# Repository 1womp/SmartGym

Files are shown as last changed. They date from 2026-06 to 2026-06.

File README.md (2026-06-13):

# SmartGym Adaptive Training System

Language: English | [Espanol](README.es.md)

SmartGym is an ESP32-S3 adaptive training prototype for selectorized gym machines. It combines RFID user identification, a touchscreen LVGL interface, range-of-motion tracking, rep and set detection, guided calibration, user-specific load recommendations, Firebase Realtime Database synchronization, a React dashboard, and a separate weight-detection prototype.

The current repository keeps the PlatformIO firmware project at the repository root so the existing build commands and include paths continue to work. Companion project assets are organized in `dashboard/`, `weight_detection/`, `docs/`, `hardware/`, and `screenshots/`.

## Start Here

If you are new to the project, start with [docs/START_HERE.md](docs/START_HERE.md). It explains what to read first, where every subsystem lives, and how the data flows from sensors to Firebase and the dashboard.

Fast paths:

| Goal | Open |
| --- | --- |
| Build and upload firmware | [Developer Guide](docs/DEVELOPER_GUIDE.md) |
| Understand ROM, calibration, equations, and error sources | [Measurement and Calibration Guide](docs/MEASUREMENT_AND_CALIBRATION_GUIDE.md) |
| Use the device in a demo | [User Manual](docs/USER_MANUAL.md) |
| Configure Firebase and understand upload paths | [Firebase Guide](docs/FIREBASE_GUIDE.md) |
| Understand dashboard seed/test data | [Firebase Dashboard Seed Guide](docs/FIREBASE_DASHBOARD_SEED_GUIDE.md) |
| Find CAD/STL hardware files | [hardware/cad/README.md](hardware/cad/README.md) |
| Run the web dashboard | [dashboard/README.md](dashboard/README.md) |
| Test the VL53L0X prototype | [weight_detection/README.md](weight_detection/README.md) |

## Key Features

- RFID user identification with MFRC522.
- ESP32-S3 touchscreen interface using LVGL.
- Analog ROM tracking with 5 ms sensor sampling, approximately 200 Hz.
- Live motion graph refreshed at approximately 16 ms, about 60 Hz.
- Rep and set detection from normalized ROM.
- Guided calibration for user-specific ROM and load recommendations.
- Manual machine pin load model: the user updates the physical pin value with buttons.
- Separate user-specific recommended load.
- Firebase RTDB sync for profiles, calibration, sessions, summaries, and device heartbeat.
- Local NVS upload queue for offline/retry behavior.
- Web dashboard for Firebase workout data.
- Separate VL53L0X weight-detection prototype module.

## System Architecture

```mermaid
flowchart LR
  Sensor[Motion sensor] --> ESP32[ESP32-S3 firmware]
  RFID[RFID reader] --> ESP32
  Touch[Touchscreen UI] <--> ESP32
  ESP32 --> NVS[Local NVS queue]
  ESP32 --> Firebase[Firebase RTDB]
  Firebase --> Dashboard[React dashboard]
  Weight[VL53L0X weight detection prototype] -. future integration .-> ESP32
```

The firmware reads motion, normalizes ROM, detects reps, records sessions, computes summary metrics, updates recommendations, stores pending uploads locally, and synchronizes with Firebase. The dashboard reads Firebase paths to visualize user training history.

## Hardware List

- ESP32-S3 VIEWE 7 inch display board.
- RGB touchscreen display supported by ESP32 Display Panel and LVGL.
- MFRC522 RFID reader.
- Analog motion/position sensor connected to GPIO 17.
- Optional VL53L0X distance sensor for the teammate weight-detection prototype.
- Selectorized gym machine with physical weight pin.
- Wi-Fi network with Firebase RTDB access.

## Software Stack

- PlatformIO.
- Arduino framework for ESP32.
- LVGL 8.4.0.
- ESP32_Display_Panel and ESP32_IO_Expander.
- MFRC522.
- FirebaseClient and ESP_SSLClient.
- React, Vite, Firebase Web SDK, and Recharts for the dashboard.

## Repository Structure

```text
.
|-- boards/                 PlatformIO board definition
|-- dashboard/              Teammate React/Vite Firebase dashboard
|-- docs/                   User, developer, Firebase, architecture, troubleshooting docs
|-- firebase_seed/          Safe Firebase seed/import artifacts
|-- hardware/               Wiring and sensor notes
|-- lib/                    Firmware libraries
|-- sample_data/            Firebase/sample data artifacts
|-- screenshots/            Screenshots or demo photos
|-- scripts/                Utility scripts
|-- src/                    Firmware application source
|-- tools/                  Local tooling
|-- weight_detection/       Teammate VL53L0X weight-detection prototype
|-- platformio.ini          Firmware build configuration
`-- README.md
```

## What Each Folder Is For

| Folder | Purpose |
| --- | --- |
| `src/` and `lib/` | ESP32-S3 firmware application and support modules. |
| `docs/` | Human-readable guides for usage, architecture, calibration, Firebase, and troubleshooting. |
| `hardware/` | Wiring notes plus CAD/STL files for mounts, enclosure parts, and ToF hardware. |
| `dashboard/` | React/Vite dashboard that reads Firebase workout data. |
| `firebase_seed/` | Safe Firebase seed/import artifacts and import instructions. |
| `weight_detection/` | Standalone VL53L0X prototype sketch for weight-stack detection experiments. |
| `sample_data/` | Firebase/sample data artifacts used for testing and dashboard demos. |
| `screenshots/` | Demo photos, UI screenshots, dashboard captures, and wiring images. |
| `tools/` and `scripts/` | Local generation, validation, and documentation utilities. |

## Documentation

The full documentation package is indexed in [docs/README.md](docs/README.md).

Most important PDFs:

- [User Manual](docs/USER_MANUAL.pdf)
- [System Architecture](docs/SYSTEM_ARCHITECTURE.pdf)
- [Developer Guide](docs/DEVELOPER_GUIDE.pdf)
- [Measurement and Calibration Guide](docs/MEASUREMENT_AND_CALIBRATION_GUIDE.md)
- [Firebase Guide](docs/FIREBASE_GUIDE.pdf)
- [Firebase Dashboard Seed Guide](docs/FIREBASE_DASHBOARD_SEED_GUIDE.md)
- [Troubleshooting Guide](docs/TROUBLESHOOTING.pdf)

## Quick Start

### Firmware

Install PlatformIO, connect the ESP32-S3 display board, then build:

```powershell
python -m platformio run --environment BOARD_VIEWE_UEDX80480070E_WB_A
```

Upload and monitor:

```powershell
python -m platformio run --target upload --target monitor --environment BOARD_VIEWE_UEDX80480070E_WB_A
```

### Dashboard

```powershell
cd dashboard
npm install
copy .env.example .env
npm run dev
```

Fill `.env` with the Firebase web config before running. Open the local Vite URL shown in the terminal. The dashboard reads Firebase RTDB data such as `usersByRfid` and `athleteWeeklySessions`.

### Weight Detection Prototype

The VL53L0X prototype is in `weight_detection/`. It is not merged into the firmware. Use it as a separate Arduino sketch for validating optical/distance-based weight-stack detection.

## Device Usage Overview

1. Power on the ESP32 display.
2. Wait for UI, Wi-Fi, Firebase, RFID, and time services.
3. Scan an RFID card.
4. Wait until the loading popup finishes profile, calibration, recommendation, and ROM mapping.
5. Check the pin load and recommended load.
6. Physically move the machine pin if desired, then update the pin load with the four buttons.
7. Press START.
8. Follow the motion graph and timing cues.
9. Finish the workout or let target sets complete.
10. Review the summary while the session syncs.

## Calibration Overview

Calibration is user-specific and machine-type-specific. It records clean reps at one or more loads, estimates ROM and performance quality, and saves recommended loads under `calibrations/{uid}/{machineTypeId}`. The physical pin is never moved automatically by software; the user adjusts the machine pin and confirms the displayed pin load.

For the full signal path, formulas, ROM normalization logic, calibration flow,
error sources, and validation steps, see
[docs/MEASUREMENT_AND_CALIBRATION_GUIDE.md](docs/MEASUREMENT_AND_CALIBRATION_GUIDE.md).

## Data Model Overview

Primary Firebase nodes:

- `usersByRfid/{uid}`
- `calibrations/{uid}/{machineTypeId}`
- `machineConfigs/{machineId}`
- `athleteWeeklySessions/{uid}/{weekKey}/days/{dayKey}`
- `devices/{deviceId}`

Session uploads include a root session record, daily metadata, timeline entries, day/week summaries, representative reps, set details, and per-set rep details under `repSets`.

## Known Limitations

- The firmware currently uses a manual pin load model; there is no integrated physical weight sensor in the main firmware.
- Firebase/TLS writes are memory-sensitive on ESP32, so uploads are queued and chunked.
- Dashboard Firebase configuration is loaded from local environment variables and should not be committed.
- The weight-detection module is a prototype and requires machine-specific calibration.

## Future Improvements

- Integrate physical weight detection after validation.
- Add production Firebase security rules and auth flow.
- Add automated firmware integration tests where practical.
- Add dashboard deployment instructions and screenshots.
- Add machine-specific wiring diagrams.

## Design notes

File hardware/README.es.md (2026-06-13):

# Notas De Hardware

Idioma: [English](README.md) | Espanol

## Hardware Principal Del Firmware

- Pantalla ESP32-S3 VIEWE de 7 pulgadas.
- Pantalla tactil RGB usando ESP32 Display Panel y LVGL.
- Lector RFID MFRC522.
- Sensor analogico ROM/motion conectado a GPIO 17.
- Red Wi-Fi para sincronizacion Firebase RTDB.

## Pines Del Firmware

Constantes actuales:

- Entrada de sensor de movimiento: GPIO 17.
- Intervalo de muestreo: 5 ms.
- RFID SS: GPIO 10.
- RFID SCK: GPIO 12.
- RFID MISO: GPIO 13.
- RFID MOSI: GPIO 11.
- RFID reset no usa pin dedicado.

## CAD E Impresion 3D

Archivos SolidWorks editables y exportes STL para mounts y enclosure estan en [`hardware/cad`](cad/).

Para ROM, conversion de senal, calibracion, fuentes de error y validacion, lee [`docs/MEASUREMENT_AND_CALIBRATION_GUIDE.es.md`](../docs/MEASUREMENT_AND_CALIBRATION_GUIDE.es.md).

## Prototipo De Deteccion De Peso

El modulo separado `weight_detection/` usa VL53L0X:

- VCC -> 3.3 V.
- GND -> GND.
- SDA -> GPIO 21.
- SCL -> GPIO 22.

Este prototipo no forma parte del firmware principal de produccion todavia.

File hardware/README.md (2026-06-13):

# Hardware Notes

Language: English | [Espanol](README.es.md)

## Main Firmware Hardware

- ESP32-S3 VIEWE 7 inch display board.
- RGB touchscreen display using ESP32 Display Panel and LVGL.
- MFRC522 RFID reader.
- Analog ROM/motion sensor connected to GPIO 17.
- Wi-Fi network for Firebase RTDB sync.

## Firmware Pin Notes

Current firmware constants:

- Motion sensor input: GPIO 17.
- Sensor sample interval: 5 ms.
- RFID SS: GPIO 10.
- RFID SCK: GPIO 12.
- RFID MISO: GPIO 13.
- RFID MOSI: GPIO 11.
- RFID reset is not used as a dedicated pin.

## CAD and 3D Printing Files

Editable SolidWorks parts and STL exports for the prototype mounts and display
enclosure are available in [`hardware/cad`](cad/).

For the full explanation of ROM measurement, signal conversion, calibration,
error sources, and validation, see
[`docs/MEASUREMENT_AND_CALIBRATION_GUIDE.md`](../docs/MEASUREMENT_AND_CALIBRATION_GUIDE.md).

## Weight Detection Prototype

The separate `weight_detection/` module uses a VL53L0X sensor:

- VCC -> 3.3 V.
- GND -> GND.
- SDA -> GPIO 21.
- SCL -> GPIO 22.

This prototype is not part of the production firmware path yet.

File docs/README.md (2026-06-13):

# SmartGym Documentation

Language: English | [Espanol](README.es.md)

This folder contains the documentation package for the SmartGym v1.0 prototype. Each major guide is available as editable Markdown and as a formatted PDF.

## Start Here

- [Start Here](START_HERE.md)
- [Project README](../README.md)
- [User Manual](USER_MANUAL.md) | [PDF](USER_MANUAL.pdf)
- [System Architecture](SYSTEM_ARCHITECTURE.md) | [PDF](SYSTEM_ARCHITECTURE.pdf)
- [Developer Guide](DEVELOPER_GUIDE.md) | [PDF](DEVELOPER_GUIDE.pdf)
- [Measurement and Calibration Guide](MEASUREMENT_AND_CALIBRATION_GUIDE.md)
- [Firebase Guide](FIREBASE_GUIDE.md) | [PDF](FIREBASE_GUIDE.pdf)
- [Troubleshooting Guide](TROUBLESHOOTING.md) | [PDF](TROUBLESHOOTING.pdf)

## Reference Documents

| Document | Markdown | PDF |
| --- | --- | --- |
| Start Here | [Open](START_HERE.md) | PDF can be generated locally |
| Measurement and Calibration Guide | [Open](MEASUREMENT_AND_CALIBRATION_GUIDE.md) | PDF can be generated locally |
| Firebase Dashboard Seed Guide | [Open](FIREBASE_DASHBOARD_SEED_GUIDE.md) | [PDF](FIREBASE_DASHBOARD_SEED_GUIDE.pdf) |
| Firebase Dashboard Seed Guide ES | [Abrir](FIREBASE_DASHBOARD_SEED_GUIDE.es.md) | PDF can be generated locally |

## Find Information By Task

| Task | Best Document |
| --- | --- |
| Understand the whole project quickly | [Start Here](START_HERE.md) |
| Operate the physical device | [User Manual](USER_MANUAL.md) |
| Explain ROM, calibration, formulas, noise, and errors | [Measurement and Calibration Guide](MEASUREMENT_AND_CALIBRATION_GUIDE.md) |
| Understand firmware modules and runtime flow | [System Architecture](SYSTEM_ARCHITECTURE.md) |
| Build, upload, debug, or modify firmware | [Developer Guide](DEVELOPER_GUIDE.md) |
| Understand Firebase paths and upload phases | [Firebase Guide](FIREBASE_GUIDE.md) |
| Understand Firebase/dashboard seed data | [Firebase Dashboard Seed Guide](FIREBASE_DASHBOARD_SEED_GUIDE.md) |
| Diagnose failed builds, RFID, ROM, sync, or dashboard issues | [Troubleshooting Guide](TROUBLESHOOTING.md) |
| Find 3D-printable files and CAD sources | [Hardware CAD README](../hardware/cad/README.md) |
| Run the dashboard | [Dashboard README](../dashboard/README.md) |
| Use the standalone ToF prototype | [Weight Detection README](../weight_detection/README.md) |

## Recommended Reading Order

1. Read [Start Here](START_HERE.md) for the project map.
2. Read the [User Manual](USER_MANUAL.md) to understand how the device is used.
3. Read the [Measurement and Calibration Guide](MEASUREMENT_AND_CALIBRATION_GUIDE.md) to understand ROM, rep detection, calibration, and error sources.
4. Read the [System Architecture](SYSTEM_ARCHITECTURE.md) for the full data flow.
5. Read the [Developer Guide](DEVELOPER_GUIDE.md) before changing firmware.
6. Read the [Firebase Guide](FIREBASE_GUIDE.md) before importing, editing, or migrating database data.
7. Read the [Firebase Dashboard Seed Guide](FIREBASE_DASHBOARD_SEED_GUIDE.md) before loading demo dashboard data.
8. Use the [Troubleshooting Guide](TROUBLESHOOTING.md) during demos and hardware testing.

## Regenerating PDFs

Run this from the repository root:

```powershell
python tools/generate_docs_pdfs.py
```

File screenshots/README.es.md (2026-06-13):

# Capturas

Idioma: [English](README.md) | Espanol

Coloca en esta carpeta capturas del proyecto, imagenes del dashboard, fotos de cableado e imagenes de demo.

Archivos sugeridos:

- `main-ui-ready.jpg`
- `main-ui-training.jpg`
- `calibration-screen.jpg`
- `summary-sync.jpg`
- `dashboard-overview.jpg`

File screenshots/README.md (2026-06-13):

# Screenshots

Language: English | [Espanol](README.es.md)

Place project screenshots, dashboard captures, wiring photos, and demo images in this folder.

Suggested files:

- `main-ui-ready.jpg`
- `main-ui-training.jpg`
- `calibration-screen.jpg`
- `summary-sync.jpg`
- `dashboard-overview.jpg`

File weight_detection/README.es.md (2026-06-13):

# Prototipo De Deteccion De Peso

Idioma: [English](README.md) | Espanol

Esta carpeta contiene un prototipo independiente para detectar la posicion fisica del stack de pesas con un sensor de distancia VL53L0X.

Esta separado intencionalmente del firmware principal SmartGym. El firmware principal actualmente usa un modelo manual de pin load, donde el usuario actualiza la carga mostrada con botones tactiles.

## Que Hace

- Lee distancia desde VL53L0X por I2C.
- Promedia 30 muestras por ciclo.
- Mapea rangos de distancia a posiciones del stack.
- Mapea posiciones a peso detectado en libras.
- Confirma peso final despues de detecciones consistentes.
- Imprime distancia, stack, peso detectado, peso confirmado y estado por Serial.

## Hardware

- ESP32 o board Arduino compatible.
- Sensor VL53L0X.
- Cableado recomendado:
  - VCC -> 3.3 V
  - GND -> GND
  - SDA -> GPIO 21
  - SCL -> GPIO 22

## Dependencias

Instala la libreria Adafruit VL53L0X en Arduino IDE o PlatformIO:

- `Adafruit_VL53L0X`

## Como Correrlo

1. Abre `weight_detection_vl53l0x.ino` en Arduino IDE.
2. Instala la libreria VL53L0X.
3. Selecciona board y puerto ESP32.
4. Sube el sketch.
5. Abre Serial Monitor a 115200 baud.

## Salida Esperada

Serial imprime:

- distancia promedio en cm
- peso detectado en lb
- peso final confirmado
- contador de confirmacion
- numero de stack
- mensajes de estado

## Relacion Con Firmware SmartGym

El modulo puede convertirse en reemplazo o apoyo para entrada manual de pin load. Antes de integrarlo, los rangos distancia-peso deben calibrarse para la geometria exacta de la maquina.

## Limitaciones

- Rangos de distancia hard-coded y especificos por maquina.
- Valores actuales en libras, mientras la UI principal usa kg.
- No esta integrado con Firebase.
- No cambia recomendaciones SmartGym.
- No debe mezclarse al firmware hasta estabilizar montaje fisico y conversion.

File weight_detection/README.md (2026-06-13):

# Weight Detection Prototype

Language: English | [Espanol](README.es.md)

This folder contains a standalone teammate prototype for detecting the physical weight-stack position with a VL53L0X time-of-flight distance sensor.

It is intentionally kept separate from the main ESP32 SmartGym firmware. The production firmware currently uses a manual machine pin load model, where the user updates the displayed pin load with the touchscreen buttons.

## What It Does

- Reads distance from a VL53L0X sensor over I2C.
- Averages 30 samples per measurement cycle.
- Maps distance ranges to stack positions.
- Maps stack positions to detected weight values in pounds.
- Confirms the final detected weight after repeated consistent detections.
- Prints distance, detected stack, detected weight, final confirmed weight, and status to Serial.

## Hardware

- ESP32 or compatible Arduino board.
- VL53L0X distance sensor.
- Recommended wiring in the sketch:
  - VCC -> 3.3 V
  - GND -> GND
  - SDA -> GPIO 21
  - SCL -> GPIO 22

## Dependencies

Install the Adafruit VL53L0X library in Arduino IDE or PlatformIO:

- `Adafruit_VL53L0X`

## How to Run

1. Open `weight_detection_vl53l0x.ino` in Arduino IDE.
2. Install the VL53L0X library.
3. Select the ESP32 board and port.
4. Upload the sketch.
5. Open Serial Monitor at 115200 baud.

## Expected Output

The serial monitor prints:

- Average distance in cm.
- Detected weight in lb.
- Final confirmed weight.
- Confirmation counter.
- Detected stack number.
- Status messages.

## Relationship to SmartGym Firmware

The module can become a future replacement or helper for manual pin-load entry. Before integration, the distance-to-weight ranges must be calibrated for the exact machine geometry and weight stack.

## Limitations

- Distance ranges are hard-coded and machine-specific.
- Values are currently in pounds, while the main firmware UI uses kg.
- The module is not integrated with Firebase.
- The module does not change SmartGym recommendations.
- The module should not be merged into firmware until the physical sensor mounting and conversion model are stable.

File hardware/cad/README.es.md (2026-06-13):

# Archivos CAD SmartGym

Idioma: [English](README.md) | Espanol

Esta carpeta contiene archivos SolidWorks, STEP y STL usados para mounts, piezas impresas y enclosure del prototipo.

## Buscador Rapido

| Necesidad | Usar |
| --- | --- |
| Montar el encoder draw-wire | `encodermount.STL` |
| Sujetar hardware a la maquina | `gymmachineclamp.STL` |
| Imprimir enclosure de pantalla | `screen7inchbackplate.STL`, `screen7inchcover.STL`, `screen7inchfrontcover.STL` |
| Montar el sensor ToF | `tof_sensor_holder_nuevo_en mm.STL`, `Fastener.stl`, `Target.stl` |
| Editar CAD fuente | archivos `.SLDPRT` o `.step` |

## Lista Completa

| Archivo | Descripcion |
| --- | --- |
| `encodermount.SLDPRT` | Fuente SolidWorks del mount del encoder. |
| `encodermount.STL` | Export imprimible del mount del encoder. |
| `gymmachineclamp.SLDPRT` | Fuente SolidWorks del clamp de maquina. |
| `gymmachineclamp.STL` | Export imprimible del clamp. |
| `machinetube.SLDPRT` | Referencia/modelo del tubo de maquina. |
| `screen7inch.SLDPRT` | Referencia de pantalla de 7 pulgadas. |
| `screen7inchbackplate.STL` | Placa trasera imprimible. |
| `screen7inchcover.STL` | Cover imprimible de pantalla. |
| `screen7inchfrontcover.SLDPRT` | Fuente SolidWorks del frente de pantalla. |
| `screen7inchfrontcover.STL` | Export imprimible del frente. |
| `Target.step` | Fuente STEP de target ToF. |
| `Target.stl` | Export imprimible de target ToF. |
| `Fastener.step` | Fuente STEP del fastener ToF. |
| `Fastener.stl` | Export imprimible del fastener ToF. |
| `tof_sensor_holder_nuevo_en mm.SLDPRT` | Fuente SolidWorks del holder ToF actualizado. |
| `tof_sensor_holder_nuevo_en mm.STL` | Export imprimible del holder ToF actualizado. |

Los `.SLDPRT` y `.step` son editables. Los `.STL` son para slicing e impresion 3D.

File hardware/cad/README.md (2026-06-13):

# SmartGym CAD Files

Language: English | [Espanol](README.es.md)

This folder contains the SolidWorks part files and STL exports used for the
prototype hardware mounts and 3D-printed enclosure pieces.

## Files

## Quick Finder

| Need | Use |
| --- | --- |
| Mount the draw-wire encoder | `encodermount.STL` |
| Clamp hardware to the gym machine | `gymmachineclamp.STL` |
| Print the display enclosure | `screen7inchbackplate.STL`, `screen7inchcover.STL`, `screen7inchfrontcover.STL` |
| Mount the ToF sensor | `tof_sensor_holder_nuevo_en mm.STL`, `Fastener.stl`, `Target.stl` |
| Edit CAD sources | `.SLDPRT` or `.step` files |

## Full File List

| File | Description |
| --- | --- |
| `encodermount.SLDPRT` | SolidWorks source for the draw-wire encoder mount. |
| `encodermount.STL` | 3D-printable encoder mount export. |
| `gymmachineclamp.SLDPRT` | SolidWorks source for the gym machine clamp. |
| `gymmachineclamp.STL` | 3D-printable gym machine clamp export. |
| `machinetube.SLDPRT` | SolidWorks source for the machine tube reference/model. |
| `screen7inch.SLDPRT` | SolidWorks source/reference model for the 7-inch display. |
| `screen7inchbackplate.STL` | 3D-printable rear plate for the 7-inch display enclosure. |
| `screen7inchcover.STL` | 3D-printable display cover export. |
| `screen7inchfrontcover.SLDPRT` | SolidWorks source for the display front cover. |
| `screen7inchfrontcover.STL` | 3D-printable display front cover export. |
| `Target.step` | STEP source for the ToF target piece. |
| `Target.stl` | 3D-printable export for the ToF target piece. |
| `Fastener.step` | STEP source for the ToF holder fastener. |
| `Fastener.stl` | 3D-printable export for the ToF holder fastener. |
| `tof_sensor_holder_nuevo_en mm.SLDPRT` | SolidWorks source for the updated ToF sensor holder. |
| `tof_sensor_holder_nuevo_en mm.STL` | 3D-printable export for the updated ToF sensor holder. |

The `.SLDPRT` files are editable CAD sources. The `.STL` files are exported
for slicing and 3D printing.

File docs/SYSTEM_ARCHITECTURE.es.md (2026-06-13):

# Arquitectura Del Sistema SmartGym

Idioma: [English](SYSTEM_ARCHITECTURE.md) | Espanol

## Arquitectura General

```mermaid
flowchart LR
  Motion[Sensor de movimiento] --> SensorManager
  SensorManager --> ROM[Normalizacion ROM]
  ROM --> RepDetector
  RepDetector --> SessionRecorder
  RFID[Lector RFID] --> UserSync[Sync de usuario]
  UserSync --> Recommendation
  Recommendation --> UI[UI LVGL]
  SessionRecorder --> UploadQueue[Cola NVS]
  UploadQueue --> Firebase[Firebase RTDB]
  Firebase --> Dashboard[Dashboard React]
```

El sistema se divide en firmware embebido, Firebase RTDB y visualizacion en dashboard.

## Flujo De Datos

1. El sensor se muestrea cada 5 ms.
2. `SensorManager` filtra el valor analogico.
3. El firmware convierte la lectura a porcentaje ROM.
4. La calibracion de usuario mapea ROM crudo a ROM normalizado.
5. `RepDetector` identifica fases y repeticiones completas.
6. `SessionRecorder` guarda reps, sets, peso, ROM, tiempos y calidad.
7. `SmartGymTouchApp` calcula resumen y recomendacion.
8. La cola de subida guarda payloads Firebase.
9. `FirebaseService` envia escrituras seguras a RTDB.
10. El dashboard lee Firebase para graficas y resumenes.

## Flujo De Login

```mermaid
sequenceDiagram
  participant U as Usuario
  participant R as RFID
  participant D as Dispositivo
  participant F as Firebase
  U->>R: Escanea tarjeta
  R->>D: UID
  D->>D: Muestra popup de carga
  D->>F: Lee usersByRfid/{uid}
  F-->>D: Perfil
  D->>F: Lee calibrations/{uid}/{machineTypeId}
  F-->>D: Calibracion o missing
  D->>D: Resuelve recomendacion
  D->>D: Aplica mapeo ROM
  D->>D: Oculta popup
```

Las entradas quedan bloqueadas hasta que el sync termina o cae a un fallback seguro.

## Flujo De Entrenamiento

```mermaid
sequenceDiagram
  participant U as Usuario
  participant D as Dispositivo
  participant S as SessionRecorder
  participant Q as Cola
  participant F as Firebase
  U->>D: Presiona START
  D->>S: Inicia sesion con pin load
  U->>D: Hace reps
  D->>S: Registra reps y sets
  U->>D: Termina o auto-finish
  D->>S: Cierra sesion
  D->>Q: Encola subida
  Q->>F: Sube por fases
```

## Pin Load Vs Recomendacion

Pin load es estado fisico de la maquina. Permanece con la maquina entre usuarios. La recomendacion es consejo especifico por usuario.

El firmware nunca cambia pin load por una recomendacion. El usuario mueve fisicamente el pin y actualiza la UI con botones.

## Calibracion

La calibracion usa el pin load actual y cargas sugeridas. El usuario confirma la carga fisica antes de recolectar reps. El firmware analiza repeticiones suaves, estima si la carga es adecuada y guarda datos de calibracion por usuario y maquina.

## Sync

El final de sesion agenda sync. Trabajo pesado de Firebase no ocurre dentro del cierre inmediato.

Fases:

- Core de sesion.
- Metadata.
- Timeline.
- Resumenes.
- Detalles.
- Rep sets.

La cola NVS permite reintentos y evita perdida de datos si Firebase o Wi-Fi fallan temporalmente.

## Frecuencias

- Tick principal: 4 ms.
- Muestreo sensor: 5 ms, aproximadamente 200 Hz.
- Grafica: 16 ms, aproximadamente 60 Hz.
- UI lenta: 140 ms.
- UI debug: 160 ms.
- Servicio cloud normal: 5000 ms.
- Cadencia de finish sync: aproximadamente 1200 ms.
- Heartbeat: 60000 ms.
- Timeout user sync: 12000 ms.

## Estrategia De Memoria

El ESP32-S3 tiene poca memoria durante escrituras TLS/Firebase. El firmware mide heap interno y bloque interno mas grande, y elige modo:

- Normal: payloads mas grandes.
- Constrained: payloads pequenos y repSets fragmentados.
- Critical: payloads muy pequenos o backoff.

Objetos LVGL opcionales se liberan antes de entrenamiento/subida para mejorar heap disponible.

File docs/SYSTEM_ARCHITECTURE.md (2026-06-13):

# SmartGym System Architecture

Language: English | [Espanol](SYSTEM_ARCHITECTURE.es.md)

## High-Level Architecture

```mermaid
flowchart LR
  Motion[Motion Sensor] --> SensorManager
  SensorManager --> ROM[ROM Normalization]
  ROM --> RepDetector
  RepDetector --> SessionRecorder
  RFID[RFID Reader] --> UserSync[User Sync]
  UserSync --> Recommendation
  Recommendation --> UI[LVGL UI]
  SessionRecorder --> UploadQueue[NVS Upload Queue]
  UploadQueue --> Firebase[Firebase RTDB]
  Firebase --> Dashboard[React Dashboard]
```

The system is split into embedded firmware, Firebase RTDB, and dashboard visualization.

## Data Flow

1. Sensor is sampled every 5 ms.
2. SensorManager filters the analog value.
3. Firmware converts sensor reading to ROM percentage.
4. User calibration maps raw ROM into user-normalized ROM.
5. RepDetector identifies rep phases and completed reps.
6. SessionRecorder stores reps, sets, weight, ROM, timing, and quality.
7. SmartGymTouchApp computes summary/recommendation updates.
8. Upload queue stores Firebase payloads.
9. FirebaseService sends memory-safe writes to RTDB.
10. Dashboard reads Firebase for charts and summaries.

## User Login Flow

```mermaid
sequenceDiagram
  participant U as User
  participant R as RFID
  participant D as Device
  participant F as Firebase
  U->>R: Scan card
  R->>D: UID
  D->>D: Show loading popup
  D->>F: Fetch usersByRfid/{uid}
  F-->>D: Profile
  D->>F: Fetch calibrations/{uid}/{machineTypeId}
  F-->>D: Calibration or missing
  D->>D: Resolve recommendation
  D->>D: Apply ROM mapping
  D->>D: Hide loading popup
```

Inputs are blocked until sync completes or falls back safely.

## Workout Flow

```mermaid
sequenceDiagram
  participant U as User
  participant D as Device
  participant S as SessionRecorder
  participant Q as Upload Queue
  participant F as Firebase
  U->>D: Press START
  D->>S: Start session with machine pin load
  U->>D: Perform reps
  D->>S: Record reps and sets
  U->>D: Finish or auto-finish
  D->>S: Finish session
  D->>Q: Queue upload
  Q->>F: Upload in phases
```

## Manual Pin Load vs Recommendation

Pin load is physical machine state. It stays with the machine across users. Recommendation is user-specific advice.

The firmware never changes pin load because of recommendation. The user physically changes the machine pin and updates the UI with weight buttons.

## Calibration Flow

Calibration uses the current machine pin load and suggested loads. The user confirms the physical load before collecting reps. The firmware analyzes smooth reps, estimates load suitability, and saves user-machine calibration data.

## Sync Flow

Session finish schedules sync. Heavy Firebase work is not performed inside the immediate finish path.

Sync writes:

- Core session.
- Metadata.
- Timeline.
- Summaries.
- Details.
- Rep sets.

The NVS queue allows retry and prevents data loss when Firebase or Wi-Fi is temporarily unavailable.

## Sampling and Refresh Rates

- Main app tick: 4 ms.
- Sensor sample interval: 5 ms, approximately 200 Hz.
- Graph refresh: 16 ms, approximately 60 Hz.
- Slow UI refresh: 140 ms.
- Debug UI refresh: 160 ms.
- Normal cloud service cadence: 5000 ms.
- Summary/cloud finish cadence: approximately 1200 ms.
- Device heartbeat interval: 60000 ms.
- User sync timeout: 12000 ms.

## Memory Strategy

The ESP32 is memory-constrained during TLS/Firebase writes. The firmware tracks internal heap and largest internal block, then selects upload behavior:

- Normal: larger payloads.
- Constrained: smaller payloads and chunked repSets.
- Critical: very small payloads or backoff.

Optional LVGL UI objects are freed before training/upload to improve available heap.

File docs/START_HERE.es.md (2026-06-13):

# Empieza Aqui

Idioma: [English](START_HERE.md) | Espanol

Esta pagina es la forma mas rapida de encontrar informacion de SmartGym sin buscar manualmente por carpetas.

## Que Es SmartGym

SmartGym es un prototipo con ESP32-S3 que instrumenta una maquina de gimnasio selectorizada. Lee movimiento, normaliza rango de movimiento, detecta repeticiones y series, registra sesiones, guarda calibraciones y sincroniza entrenamientos terminados con Firebase para analizarlos en un dashboard.

## Lee Primero Esto

| Necesidad | Abrir |
| --- | --- |
| Entender el proyecto en 5 minutos | [README del proyecto](../README.es.md) |
| Usar el dispositivo durante una demo | [Manual de usuario](USER_MANUAL.es.md) |
| Entender ROM, calibracion, ecuaciones y errores | [Guia de medicion y calibracion](MEASUREMENT_AND_CALIBRATION_GUIDE.es.md) |
| Entender modulos de firmware y flujo de datos | [Arquitectura del sistema](SYSTEM_ARCHITECTURE.es.md) |
| Compilar o modificar firmware | [Guia de desarrollador](DEVELOPER_GUIDE.es.md) |
| Entender Firebase y subidas | [Guia de Firebase](FIREBASE_GUIDE.es.md) |
| Entender datos seed/demo del dashboard | [Guia de seed Firebase para dashboard](FIREBASE_DASHBOARD_SEED_GUIDE.es.md) |
| Resolver problemas de hardware, sync o UI | [Troubleshooting](TROUBLESHOOTING.es.md) |
| Encontrar CAD y STL | [CAD de hardware](../hardware/cad/README.es.md) |
| Ejecutar dashboard React | [Dashboard](../dashboard/README.es.md) |
| Probar prototipo VL53L0X | [Weight Detection](../weight_detection/README.es.md) |

## Si Vas A Construir Todo El Proyecto

1. Lee el [README del proyecto](../README.es.md).
2. Compila el firmware con los comandos del README.
3. Lee la [Guia de medicion y calibracion](MEASUREMENT_AND_CALIBRATION_GUIDE.es.md).
4. Monta hardware usando [Hardware](../hardware/README.es.md) y [CAD](../hardware/cad/README.es.md).
5. Configura Firebase usando la [Guia de Firebase](FIREBASE_GUIDE.es.md).
6. Usa la [Guia de seed Firebase para dashboard](FIREBASE_DASHBOARD_SEED_GUIDE.es.md) si necesitas datos demo.
7. Ejecuta el dashboard usando [Dashboard](../dashboard/README.es.md).
8. Usa [Troubleshooting](TROUBLESHOOTING.es.md) durante pruebas de hardware.

## Flujo Principal De Datos

```text
Sensor de movimiento -> ESP32-S3 -> normalizacion ROM -> deteccion de reps
RFID -> perfil de usuario -> calibracion -> recomendacion
Session recorder -> cola NVS -> Firebase RTDB -> dashboard React
```

## Conceptos Clave

| Concepto | Explicacion corta | Detalles |
| --- | --- | --- |
| ROM | Rango de movimiento calibrado de usuario, normalizado de abajo a arriba. | [Guia de medicion y calibracion](MEASUREMENT_AND_CALIBRATION_GUIDE.es.md) |
| Pin load | Posicion fisica del pin de peso. Pertenece a la maquina, no al usuario. | [Guia de medicion y calibracion](MEASUREMENT_AND_CALIBRATION_GUIDE.es.md) |
| Carga recomendada | Consejo especifico por usuario. No mueve el pin fisico. | [Guia de medicion y calibracion](MEASUREMENT_AND_CALIBRATION_GUIDE.es.md) |
| Deteccion de reps | Maquina de estados basada en ROM: abajo, subida, arriba, bajada. | [Guia de desarrollador](DEVELOPER_GUIDE.es.md) |
| Cola Firebase | Cola local en NVS para reintentos seguros. | [Guia de Firebase](FIREBASE_GUIDE.es.md) |
| Dashboard | App React que lee historial de Firebase. | [Dashboard](../dashboard/README.es.md) |

## Donde Viven Los Archivos

| Area | Carpeta |
| --- | --- |
| Firmware ESP32-S3 | `src/`, `lib/`, `boards/`, `platformio.ini` |
| Documentacion | `docs/` |
| Dashboard | `dashboard/` |
| CAD y STL | `hardware/cad/` |
| Notas de hardware | `hardware/` |
| Sketch VL53L0X | `weight_detection/` |
| Utilidades | `scripts/`, `tools/` |
| Datos de ejemplo | `sample_data/` |

## Checklist Antes De Demo

1. Firmware compila y sube.
2. Wi-Fi conecta.
3. RFID lee un usuario conocido.
4. User sync termina antes de habilitar START.
5. Calibracion ROM se carga o se muestra fallback seguro.
6. Pin load y recomendacion aparecen separados.
7. La sesion inicia, cuenta reps y muestra resumen.
8. La subida a Firebase llega a complete.
9. El dashboard muestra la sesion.

## Confusiones Comunes

| Confusion | Modelo correcto |
| --- | --- |
| Cambio la recomendacion, entonces cambio el pin. | No. La recomendacion es consejo; el pin load es estado fisico. |
| Todo movimiento cuenta como repeticion. | No. La rep debe pasar ROM, tiempo y orden de fases. |
| Firebase sube todo en una sola request. | No. Se guarda localmente y se sube por fases. |
| El dashboard define el modelo de datos. | No. El firmware escribe; el dashboard lee. |
| El VL53L0X controla automaticamente el firmware. | No. Es prototipo separado hasta integrarse intencionalmente. |

## Seguridad

No commitees contrasenas Wi-Fi, secretos de Firebase, service accounts, tokens ni archivos `.env` privados. Usa ejemplos y variables de entorno locales.

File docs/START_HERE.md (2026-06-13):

# Start Here

Language: English | [Espanol](START_HERE.es.md)

This page is the fastest way to find the right SmartGym information without
digging through folders.

## What SmartGym Is

SmartGym is an ESP32-S3 prototype that instruments a selectorized gym machine.
It reads machine motion, normalizes range of motion, detects reps and sets,
records user sessions, stores calibration data, and syncs finished workouts to
Firebase for dashboard analysis.

## First Read These

| Need | Open |
| --- | --- |
| Understand the project in 5 minutes | [Project README](../README.md) |
| Use the device during a demo | [User Manual](USER_MANUAL.md) |
| Understand ROM, calibration, equations, and errors | [Measurement and Calibration Guide](MEASUREMENT_AND_CALIBRATION_GUIDE.md) |
| Understand firmware modules and data flow | [System Architecture](SYSTEM_ARCHITECTURE.md) |
| Build or modify firmware | [Developer Guide](DEVELOPER_GUIDE.md) |
| Understand Firebase paths and upload behavior | [Firebase Guide](FIREBASE_GUIDE.md) |
| Understand dashboard seed/test data | [Firebase Dashboard Seed Guide](FIREBASE_DASHBOARD_SEED_GUIDE.md) |
| Fix common hardware, sync, or UI problems | [Troubleshooting Guide](TROUBLESHOOTING.md) |
| Find CAD and printable hardware files | [Hardware CAD README](../hardware/cad/README.md) |
| Run the React dashboard | [Dashboard README](../dashboard/README.md) |
| Test the separate VL53L0X prototype | [Weight Detection README](../weight_detection/README.md) |

## If You Are Building the Full Project

Follow this order:

1. Read the [Project README](../README.md).
2. Build the firmware using the commands in the README.
3. Read the [Measurement and Calibration Guide](MEASUREMENT_AND_CALIBRATION_GUIDE.md).
4. Wire and mount hardware using [Hardware Notes](../hardware/README.md) and [CAD files](../hardware/cad/README.md).
5. Configure Firebase using the [Firebase Guide](FIREBASE_GUIDE.md).
6. Use the [Firebase Dashboard Seed Guide](FIREBASE_DASHBOARD_SEED_GUIDE.md) if you need demo data.
7. Run the dashboard using [Dashboard README](../dashboard/README.md).
8. Use the [Troubleshooting Guide](TROUBLESHOOTING.md) during hardware tests.

## How the Main Data Flow Works

```text
Motion sensor -> ESP32-S3 -> ROM normalization -> rep detection
RFID -> user profile -> calibration -> recommendation
Session recorder -> NVS queue -> Firebase RTDB -> React dashboard
```

## Core Concepts

| Concept | Short Explanation | Full Details |
| --- | --- | --- |
| ROM | The user's calibrated movement range, normalized from bottom to top. | [Measurement and Calibration Guide](MEASUREMENT_AND_CALIBRATION_GUIDE.md) |
| Pin load | The physical machine weight-pin position. It belongs to the machine, not the user. | [Measurement and Calibration Guide](MEASUREMENT_AND_CALIBRATION_GUIDE.md) |
| Recommended load | User-specific advice from calibration or session history. It does not move the pin. | [Measurement and Calibration Guide](MEASUREMENT_AND_CALIBRATION_GUIDE.md) |
| Rep detection | A ROM state machine that detects bottom, ascent, top, descent, and completion. | [Developer Guide](DEVELOPER_GUIDE.md) |
| Firebase queue | Local NVS-backed retry queue for safe uploads. | [Firebase Guide](FIREBASE_GUIDE.md) |
| Dashboard | React app that reads Firebase workout history. | [Dashboard README](../dashboard/README.md) |

## Where Files Live

| Area | Folder |
| --- | --- |
| ESP32-S3 firmware | `src/`, `lib/`, `boards/`, `platformio.ini` |
| Documentation | `docs/` |
| Dashboard | `dashboard/` |
| CAD and STL files | `hardware/cad/` |
| Hardware notes | `hardware/` |
| VL53L0X prototype sketch | `weight_detection/` |
| Utility scripts | `scripts/`, `tools/` |
| Firebase/sample data | `sample_data/` |

## What To Check Before a Demo

1. Firmware builds and uploads.
2. Wi-Fi connects.
3. RFID scans a known user.
4. User sync finishes before START is enabled.
5. ROM calibration is loaded or a safe fallback is shown.
6. Pin load and recommendation are displayed separately.
7. Session starts, reps count, and summary appears.
8. Firebase upload reaches complete.
9. Dashboard shows the session.

## Most Common Confusions

| Confusion | Correct Mental Model |
| --- | --- |
| Recommendation changed, so pin load changed. | No. Recommendation is advice; pin load is the physical machine state. |
| A movement always counts as a rep. | No. A rep must satisfy ROM, timing, and phase-order checks. |
| Firebase upload happens immediately in one request. | No. It is queued locally and uploaded in phases. |
| The dashboard owns the data model. | No. Firmware writes the data; dashboard reads it. |
| The VL53L0X prototype automatically controls the main firmware. | No. It is a separate prototype unless integrated intentionally. |

## Security Reminder

Do not commit real Wi-Fi passwords, Firebase secrets, service accounts, tokens,
or private `.env` files. Use example files and local environment variables.

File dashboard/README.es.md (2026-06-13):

# Dashboard SmartGym

Idioma: [English](README.md) | Espanol

Esta carpeta contiene el dashboard React/Vite para visualizar datos SmartGym desde Firebase.

## Stack

- React
- Vite
- Firebase Web SDK
- Recharts

## Setup

```powershell
cd dashboard
npm install
npm run dev
```

Build de produccion:

```powershell
npm run build
npm run preview
```

## Conexion Firebase

El dashboard inicializa Firebase en `src/firebase.js` usando variables de entorno Vite. Copia `.env.example` a `.env` localmente y llena la configuracion real. No commitees `.env`.

Rutas conocidas:

- `usersByRfid/{rfid}` para perfil.
- `athleteWeeklySessions/{rfid}` para historial.
- `athleteWeeklySessions/{rfid}/{week}/days` para calendario/graficas.
- `recommendedRoutineProgress/{rfid}/{selectedDate}` para progreso de rutina.

El firmware escribe datos bajo `athleteWeeklySessions`, incluyendo resumenes diarios, resumenes semanales, timelines, raiz de sesion, detalles de sets, reps representativas y rep sets.

Para datos demo/prueba, consulta la [Guia de seed Firebase para dashboard](../docs/FIREBASE_DASHBOARD_SEED_GUIDE.es.md). Explica el dataset generado y el flujo de importacion segura.

## Notas

- `node_modules/` no se incluye en el repo.
- Ejecuta `npm install` despues de clonar.
- Las rutas Firebase deben mantenerse compatibles con el firmware.
- Claves reales Firebase y project IDs deben quedarse en `.env` local o secretos de despliegue.

## Capturas

Agrega capturas en `../screenshots/` y referencialas aqui cuando esten disponibles.

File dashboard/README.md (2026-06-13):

# SmartGym Dashboard

Language: English | [Espanol](README.es.md)

This folder contains the teammate React/Vite dashboard for visualizing SmartGym Firebase data.

## Stack

- React
- Vite
- Firebase Web SDK
- Recharts

## Setup

```powershell
cd dashboard
npm install
npm run dev
```

For production build:

```powershell
npm run build
npm run preview
```

## Firebase Connection

The dashboard initializes Firebase in `src/firebase.js` from Vite environment variables. Copy `.env.example` to `.env` locally and fill in the real Firebase web config. Do not commit `.env`.

Current known paths used by the dashboard include:

- `usersByRfid/{rfid}` for user profile data.
- `athleteWeeklySessions/{rfid}` for weekly/day/session history.
- `athleteWeeklySessions/{rfid}/{week}/days` for calendar and charts.
- `recommendedRoutineProgress/{rfid}/{selectedDate}` for routine progress UI.

The firmware writes workout data under `athleteWeeklySessions`, including day summaries, week summaries, timelines, session roots, set details, representative reps, and rep sets.

For demo/test data, see [Firebase Dashboard Seed Guide](../docs/FIREBASE_DASHBOARD_SEED_GUIDE.md). It explains the generated dataset and safe import workflow.

## Notes

- `node_modules/` is intentionally excluded from the repository.
- Run `npm install` after cloning.
- Firebase paths should stay compatible with the firmware schema.
- Real Firebase keys and project IDs should stay in local environment files or deployment secrets.

## Screenshots

Add screenshots to `../screenshots/` and reference them here when available.

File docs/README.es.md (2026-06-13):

# Documentacion SmartGym

Idioma: [English](README.md) | Espanol

Esta carpeta contiene el paquete de documentacion del prototipo SmartGym v1.0. Cada guia importante esta disponible como Markdown editable; algunas tambien tienen PDF formateado.

## Empieza Aqui

- [Empieza Aqui](START_HERE.es.md)
- [README del proyecto](../README.es.md)
- [Manual de usuario](USER_MANUAL.es.md) | [PDF ingles](USER_MANUAL.pdf)
- [Arquitectura del sistema](SYSTEM_ARCHITECTURE.es.md) | [PDF ingles](SYSTEM_ARCHITECTURE.pdf)
- [Guia de desarrollador](DEVELOPER_GUIDE.es.md) | [PDF ingles](DEVELOPER_GUIDE.pdf)
- [Guia de medicion y calibracion](MEASUREMENT_AND_CALIBRATION_GUIDE.es.md)
- [Guia de Firebase](FIREBASE_GUIDE.es.md) | [PDF ingles](FIREBASE_GUIDE.pdf)
- [Troubleshooting](TROUBLESHOOTING.es.md) | [PDF ingles](TROUBLESHOOTING.pdf)

## Documentos De Referencia

| Documento | Markdown | PDF |
| --- | --- | --- |
| Empieza Aqui | [Abrir](START_HERE.es.md) | Se puede generar localmente |
| Guia de medicion y calibracion | [Abrir](MEASUREMENT_AND_CALIBRATION_GUIDE.es.md) | Se puede generar localmente |
| Guia de seed Firebase para dashboard | [Abrir](FIREBASE_DASHBOARD_SEED_GUIDE.es.md) | Se puede generar localmente |

## Encontrar Informacion Por Tarea

| Tarea | Mejor documento |
| --- | --- |
| Entender el proyecto completo rapidamente | [Empieza Aqui](START_HERE.es.md) |
| Operar el dispositivo fisico | [Manual de usuario](USER_MANUAL.es.md) |
| Explicar ROM, calibracion, formulas, ruido y errores | [Guia de medicion y calibracion](MEASUREMENT_AND_CALIBRATION_GUIDE.es.md) |
| Entender modulos de firmware y flujo runtime | [Arquitectura del sistema](SYSTEM_ARCHITECTURE.es.md) |
| Compilar, subir, depurar o modificar firmware | [Guia de desarrollador](DEVELOPER_GUIDE.es.md) |
| Entender rutas Firebase y fases de subida | [Guia de Firebase](FIREBASE_GUIDE.es.md) |
| Entender datos seed/demo de Firebase y dashboard | [Guia de seed Firebase para dashboard](FIREBASE_DASHBOARD_SEED_GUIDE.es.md) |
| Diagnosticar build, RFID, ROM, sync o dashboard | [Troubleshooting](TROUBLESHOOTING.es.md) |
| Encontrar archivos CAD/STL | [CAD de hardware](../hardware/cad/README.es.md) |
| Ejecutar dashboard | [Dashboard](../dashboard/README.es.md) |
| Usar prototipo ToF independiente | [Weight Detection](../weight_detection/README.es.md) |

## Orden Recomendado

1. Lee [Empieza Aqui](START_HERE.es.md) para ver el mapa del proyecto.
2. Lee el [Manual de usuario](USER_MANUAL.es.md) para entender uso del dispositivo.
3. Lee la [Guia de medicion y calibracion](MEASUREMENT_AND_CALIBRATION_GUIDE.es.md) para entender ROM, reps, calibracion y errores.
4. Lee [Arquitectura del sistema](SYSTEM_ARCHITECTURE.es.md) para entender el flujo completo.
5. Lee la [Guia de desarrollador](DEVELOPER_GUIDE.es.md) antes de modificar firmware.
6. Lee la [Guia de Firebase](FIREBASE_GUIDE.es.md) antes de importar, editar o migrar datos.
7. Lee la [Guia de seed Firebase para dashboard](FIREBASE_DASHBOARD_SEED_GUIDE.es.md) antes de cargar datos demo.
8. Usa [Troubleshooting](TROUBLESHOOTING.es.md) durante demos y pruebas de hardware.

## Regenerar PDFs

Ejecuta esto desde la raiz del repositorio:

```powershell
python tools/generate_docs_pdfs.py
```

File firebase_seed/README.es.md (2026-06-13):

# Instrucciones De Seed Firebase

Idioma: [English](README.md) | Espanol

Esta carpeta contiene archivos seed generados para flujos locales, de desarrollo y de prueba.

## Archivos

- `firebase_seed/test_database_full_seed.json`
  - Seed completo de Realtime Database solo para desarrollo/pruebas.
  - Incluye nodos como `usersByRfid`, `calibrations`, `devices`, `athleteWeeklySessions`, `machineConfigs` y `machineCatalog`.
- `firebase_seed/machineCatalog_value_only.json`
  - JSON solo de valor para el nodo `/machineCatalog`.
  - Es seguro para importacion manual a nivel de nodo si la ruta seleccionada es exactamente `/machineCatalog`.
- `tools/firebase_seed/machine_catalog_v1.json`
  - Documento fuente de catalogo de maquinas usado por los generadores.

## Reglas De Seguridad

- No importes `test_database_full_seed.json` en produccion.
- No importes ningun seed en la raiz (`/`) de una base de produccion.
- Importar JSON en la raiz puede reemplazar toda la base de datos.
- El firmware debe funcionar siempre con defaults embebidos del catalogo de maquinas.
- El catalogo en la nube es opcional y solo debe sobrescribir campos compatibles.
- Nunca ejecutes imports completos de raiz contra datos de produccion.

## Importacion Segura En Firebase Console

Para importar solo `machineCatalog`:

1. Abre Realtime Database en Firebase Console.
2. Selecciona o crea el nodo hijo `machineCatalog`.
3. Confirma que la ruta seleccionada sea exactamente `/machineCatalog`.
4. Importa `firebase_seed/machineCatalog_value_only.json`.
5. No importes este archivo en `/`.

Advertencia:
Importar JSON en la raiz de la base puede reemplazar toda la base.

## Ejemplos Opcionales Con CLI

Catalogo de maquinas solamente:

```bash
firebase database:set /machineCatalog firebase_seed/machineCatalog_value_only.json
```

Reset completo de base de prueba:

```bash
firebase database:set / firebase_seed/test_database_full_seed.json
```

No ejecutes el reset de raiz contra produccion.

## Regenerar Seeds

Ejecuta el generador existente:

```bash
python scripts/generate_firebase_week_seed.py
```

Esto actualiza:

- `sample_data/firebase_rtdb_two_week_seed_2026_w16_w17.json`
- `sample_data/firebase_rtdb_week_seed_2026_w16.json`
- `firebase_seed/test_database_full_seed.json`
- `firebase_seed/machineCatalog_value_only.json`

## Nota De Sincronizacion

Los valores de `machineCatalog` deben mantenerse alineados con los defaults de firmware en `MachineRegistry`.

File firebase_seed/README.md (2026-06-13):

# Firebase Seed Instructions

Language: English | [Espanol](README.es.md)

This folder contains generated seed files for local/dev/test workflows.

## Files

- `firebase_seed/test_database_full_seed.json`
  - Full Realtime Database seed for development/testing only.
  - Includes roots like `usersByRfid`, `calibrations`, `devices`,
    `athleteWeeklySessions`, `machineConfigs`, and `machineCatalog`.
- `firebase_seed/machineCatalog_value_only.json`
  - Value-only JSON intended for the `/machineCatalog` node only.
  - Safe for manual node-level import when the selected path is exactly `/machineCatalog`.
- `tools/firebase_seed/machine_catalog_v1.json`
  - Source machine catalog document used by seed generators.

## Safety Rules

- Do not import `test_database_full_seed.json` into production.
- Do not import any seed file at database root (`/`) in production.
- Importing JSON at root can replace the entire database.
- Firmware must always work with embedded machine catalog defaults.
- Cloud machine catalog is optional and should only override matching fields.
- Never run full-root imports against production data.

## Firebase Console Safe Import (machineCatalog only)

1. Open Realtime Database in Firebase Console.
2. Select or create the `machineCatalog` child node.
3. Confirm the selected path is exactly `/machineCatalog`.
4. Import `firebase_seed/machineCatalog_value_only.json`.
5. Do not import this file at `/`.

Warning:
Importing JSON at database root can replace the entire database.

## Optional CLI Examples (manual only)

Machine catalog only (safe path-specific update):

```bash
firebase database:set /machineCatalog firebase_seed/machineCatalog_value_only.json
```

Full test database reset (dangerous, dev/test only):

```bash
firebase database:set / firebase_seed/test_database_full_seed.json
```

Do not run the root reset command against production.

## Regenerate Seeds

Run the existing test seed generator:

```bash
python scripts/generate_firebase_week_seed.py
```

This updates:

- `sample_data/firebase_rtdb_two_week_seed_2026_w16_w17.json`
- `sample_data/firebase_rtdb_week_seed_2026_w16.json`
- `firebase_seed/test_database_full_seed.json`
- `firebase_seed/machineCatalog_value_only.json`

## Sync Note

`machineCatalog` seed values should stay in sync with firmware `MachineRegistry` defaults.

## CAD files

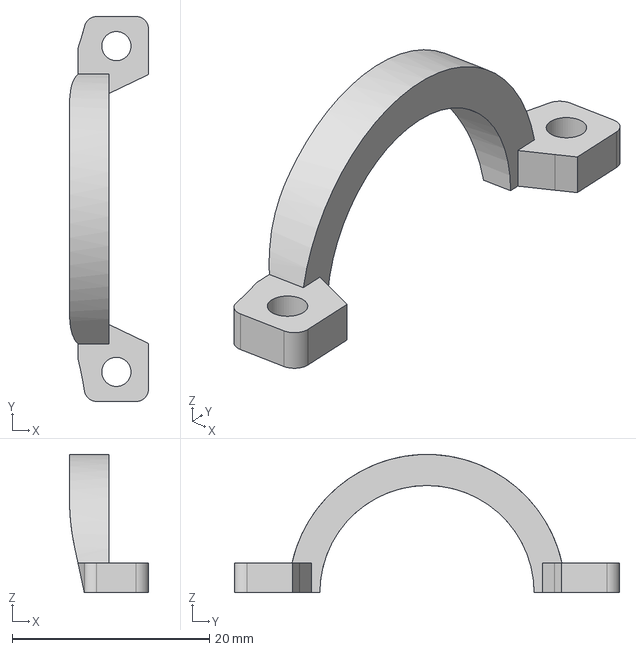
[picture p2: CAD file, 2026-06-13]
hardware/cad/Fastener.step
8.00 x 39.0 x 14.0 mm

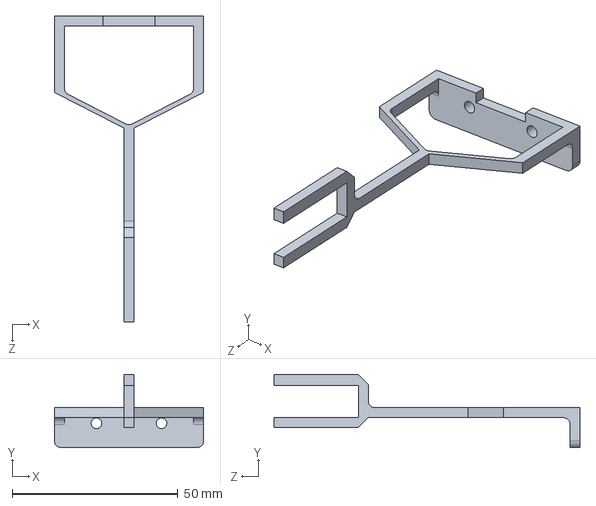
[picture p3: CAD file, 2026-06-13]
hardware/cad/tof_sensor_holder_nuevo_en mm.SLDPRT
45.0 x 22.0 x 92.2 mm

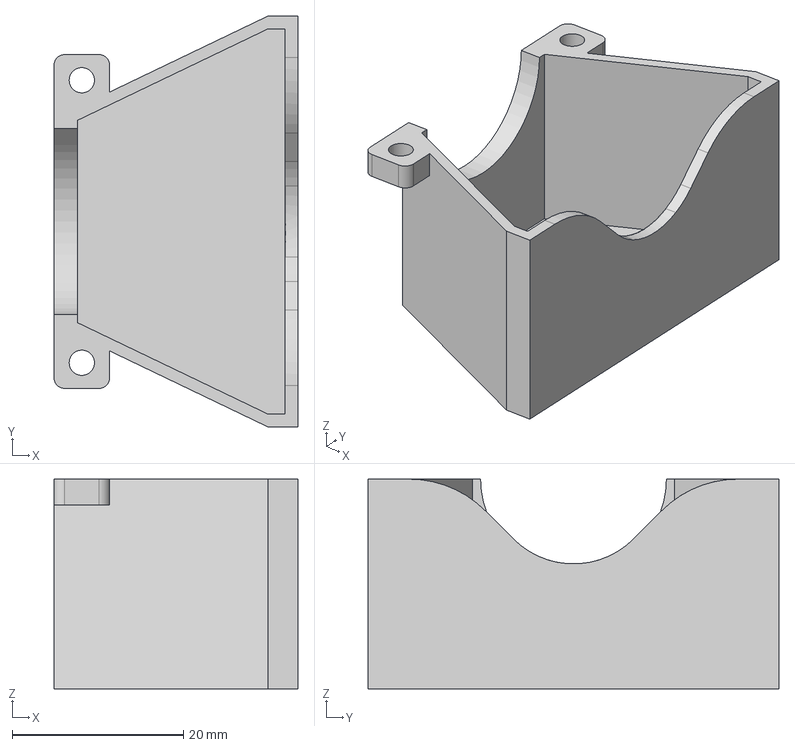
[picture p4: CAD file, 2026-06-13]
hardware/cad/Target.step
28.5 x 48.0 x 24.5 mm

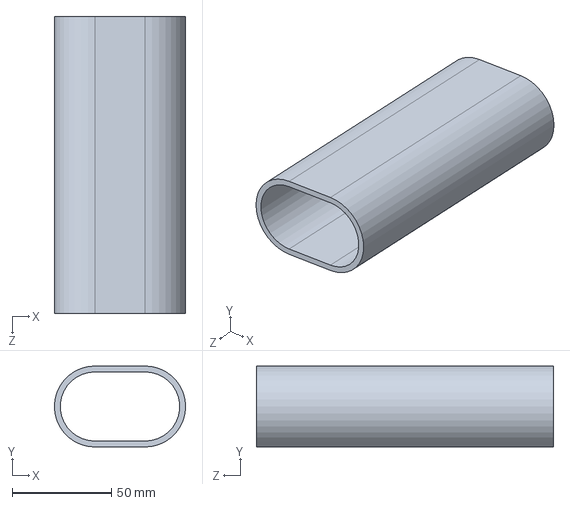
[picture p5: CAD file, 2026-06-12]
hardware/cad/machinetube.SLDPRT
66.3 x 40.9 x 150.0 mm

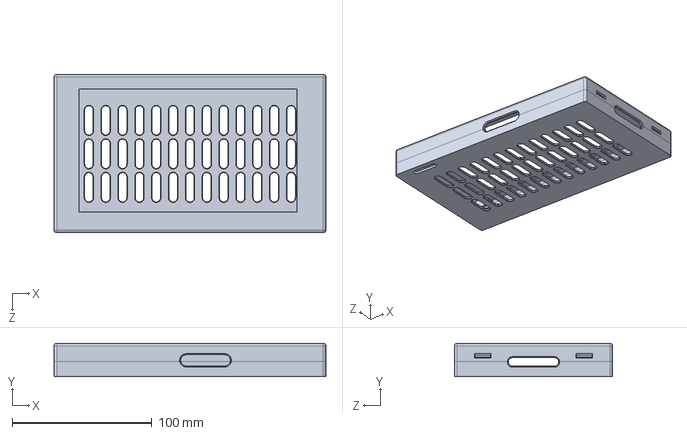
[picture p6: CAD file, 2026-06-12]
hardware/cad/screen7inchfrontcover.SLDPRT
194.9 x 24.0 x 113.4 mm

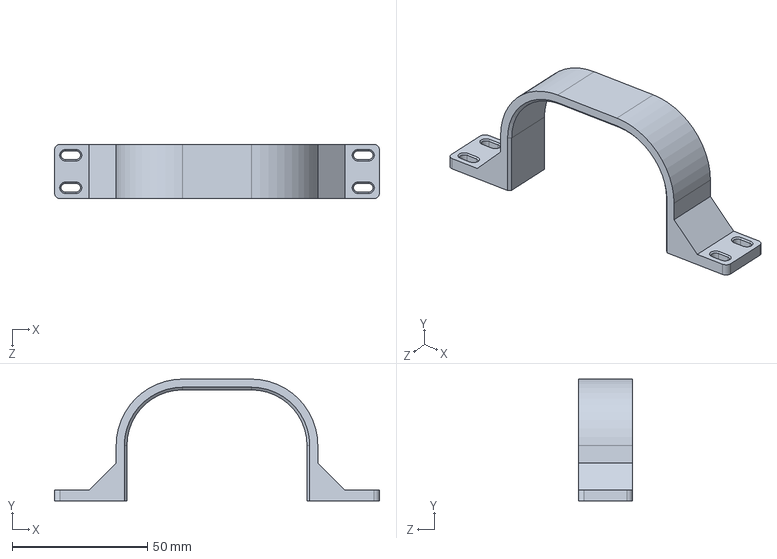
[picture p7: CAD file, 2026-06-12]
hardware/cad/gymmachineclamp.SLDPRT
120.0 x 45.0 x 20.0 mm

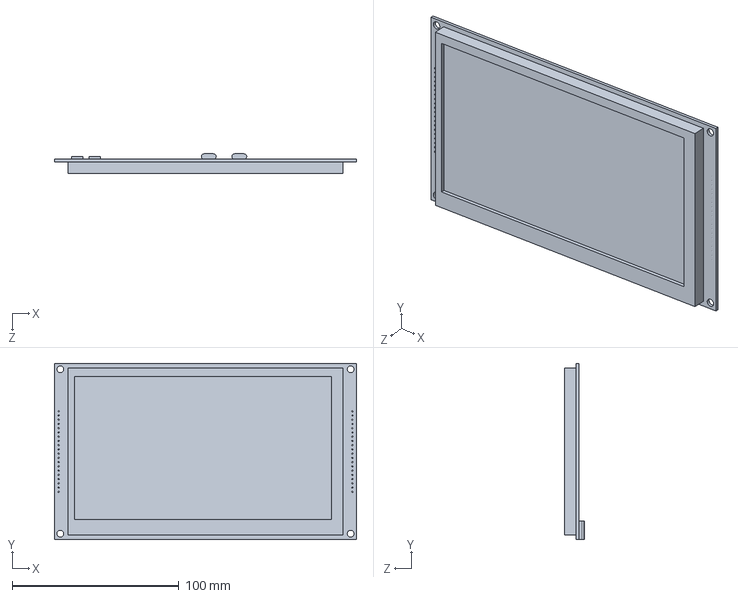
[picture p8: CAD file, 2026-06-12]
hardware/cad/screen7inch.SLDPRT
180.9 x 105.4 x 11.7 mm

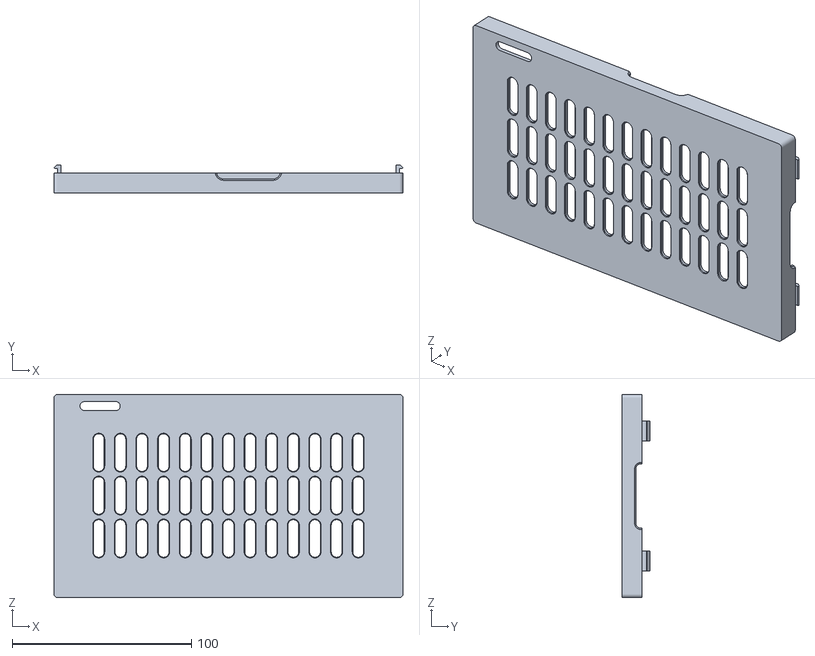
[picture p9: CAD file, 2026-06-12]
hardware/cad/screen7inchbackplate.STL
194.9 x 15.5 x 113.4

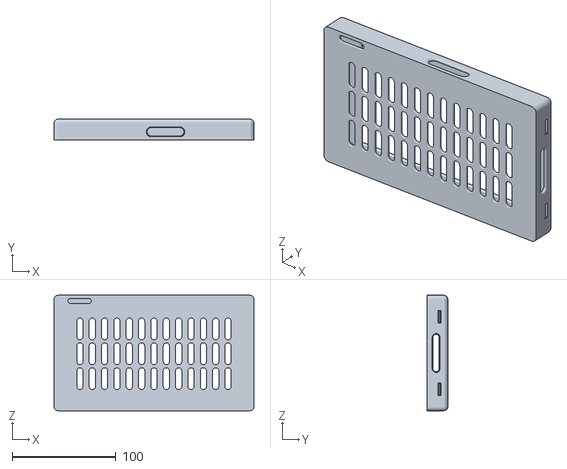
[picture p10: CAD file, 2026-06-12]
hardware/cad/screen7inchcover.STL
192.9 x 20.0 x 111.5

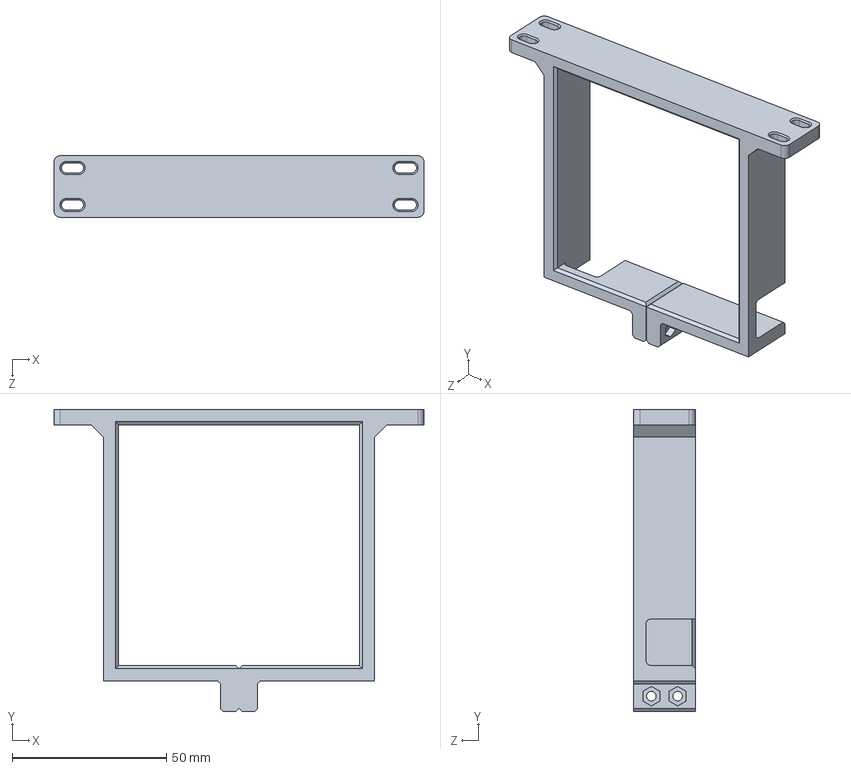
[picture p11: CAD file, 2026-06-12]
hardware/cad/encodermount.SLDPRT
120.0 x 98.0 x 20.0 mm

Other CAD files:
hardware/cad/Fastener.stl
hardware/cad/Target.stl
hardware/cad/encodermount.STL
hardware/cad/gymmachineclamp.STL
hardware/cad/screen7inchfrontcover.STL
hardware/cad/tof_sensor_holder_nuevo_en mm.STL

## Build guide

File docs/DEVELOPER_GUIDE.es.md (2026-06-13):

# Guia De Desarrollador SmartGym

Idioma: [English](DEVELOPER_GUIDE.md) | Espanol

## Entorno De Desarrollo

El firmware es un proyecto PlatformIO Arduino para una pantalla ESP32-S3 VIEWE.

Environment requerido:

```text
BOARD_VIEWE_UEDX80480070E_WB_A
```

Build:

```powershell
python -m platformio run --environment BOARD_VIEWE_UEDX80480070E_WB_A
```

Para builds locales, proporciona Wi-Fi/Firebase privados mediante build flags o configuracion local no trackeada. No commitees SSID, passwords, tokens, service accounts ni configuracion privada.

Upload y monitor:

```powershell
python -m platformio run --target upload --target monitor --environment BOARD_VIEWE_UEDX80480070E_WB_A
```

## Layout Del Repositorio

- `src/`: codigo de aplicacion.
- `lib/`: modulos firmware.
- `boards/`: configuracion de board.
- `dashboard/`: dashboard React.
- `weight_detection/`: prototipo VL53L0X.
- `docs/`: documentacion.
- `hardware/`: notas de cableado/CAD.
- `screenshots/`: imagenes de demo.

## Arquitectura Principal

`SmartGymTouchApp` coordina estado de UI, entrenamiento, calibracion, user sync, cola Firebase y guards de memoria.

Estados principales:

- Idle/Ready.
- Calibration.
- Training.
- Summary.

Pantallas:

- Main.
- Summary.
- Idle.
- Calibration.
- Calibration gate.
- Debug.
- Profile.

## Modulos

### SmartGymTouchApp

Coordina:

- creacion/refresco LVGL
- RFID
- sync de perfil/calibracion
- normalizacion ROM
- reps
- calibracion
- inicio/fin de sesion
- agenda de Firebase
- chunking por memoria

### SensorManager

Lee el sensor analogico y lo convierte a ROM filtrado. Muestreo: 5 ms, aproximadamente 200 Hz.

### RepDetector

Maquina de estados:

- Bottom
- Ascending
- Top
- Descending

Calcula duracion, rango ROM, velocidades, warnings e invalid flags.

### SessionRecorder

Guarda sesion activa, sets, reps, carga por rep, tiempos, ROM, calidad y payloads JSON.

Limites actuales:

- Max sets por sesion: 8.
- Max reps por sesion: 80.

### FirebaseService

Maneja rutas RTDB, JSON, lecturas, escrituras y transporte FirebaseClient.

### MachineRegistry

Guarda catalogo embebido y templates de movimiento para:

- `hypertrophy`
- `strength`
- `endurance`
- `test`

`test` se conserva para validacion device/Firebase.

### UserRegistry

Guarda perfiles locales y calibraciones usuario-maquina.

Limites:

- perfiles locales: 8
- calibraciones por perfil: 8

### LocalPersistenceStore

Usa NVS/Preferences para:

- cache de usuarios
- cache de sesiones
- cola de upload pendiente

### RfidService

Lee MFRC522 y formatea UIDs en hex mayusculo separado por `-`.

## UI

El firmware usa LVGL. Refrescos:

- tick principal: 4 ms
- chart: 16 ms
- UI lenta: 140 ms
- debug UI: 160 ms

Todo objeto LVGL de pantalla/modal debe resetearse a `nullptr` al destruir su padre para evitar crashes por punteros obsoletos.

## Calibracion

La calibracion es especifica por usuario y machine type. Flujo:

- confirmacion de carga inicial
- controles fisicos de pin load
- recoleccion de reps
- analisis de set
- siguiente carga opcional
- resultado y guardado

Se guarda en:

```text
calibrations/{uid}/{machineTypeId}
```

## Recomendacion

Recomendacion esta separada de pin load:

- pin load: estado fisico de maquina
- recomendacion: consejo especifico por usuario

La recomendacion no debe sobrescribir el pin load.

## Firebase Sync

El final de sesion agenda upload en cola.

Fases:

1. Core de sesion.
2. Day metadata.
3. Day timeline.
4. Day summary.
5. Week summary.
6. Representative reps.
7. Set details.
8. Rep sets.

## Chunking

Modos de memoria:

- Normal.
- Constrained.
- Critical.

Limites de repSet:

- Normal: target 1900 bytes, max 2100, hasta 6 reps.
- Constrained: target 900 bytes, max 1100, hasta 3 reps.
- Critical: target 650 bytes, max 850, hasta 2 reps.

La forma final en Firebase se mantiene:

```text
repSets/set1/reps/0
repSets/set1/reps/1
```

## Agregar Una Maquina

1. Agregar seed en `MachineRegistry`.
2. Definir id, type id, nombre, categoria, musculos, stroke, min/max/incremento y peso default.
3. Confirmar templates de metas y timing.
4. Recompilar firmware.
5. Verificar compatibilidad Firebase si hay overrides cloud.

## Goals

Publicos:

- `hypertrophy`
- `strength`
- `endurance`

Interno/debug:

- `test`

Legacy:

- `general`, normalizado para runtime nuevo.

No elimines `test`; sirve para pruebas device/Firebase.

## Tags De Logs

- `[BOOT]`: arranque.
- `[BOOTMEM]`: memoria.
- `[RFID]`: tarjetas.
- `[USER_SYNC]`: perfil/calibracion/recomendacion.
- `[UI_LOADING]`: popup.
- `[WEIGHT]`: pin load/recomendacion.
- `[SESSION]`: sesion, reps, sets, finish.
- `[CAL]`: logica calibracion.
- `[CAL_UI]`: UI calibracion.
- `[SYNC]`: upload/cola.
- `[SYNCGATE]`: scheduling cloud.
- `[CloudWrite]`: Firebase writes.
- `[GRAPH]`: grafica/timing.

## Memoria

Firebase/TLS puede consumir mucha memoria. Libera UI opcional antes de entrenar/subir, evita payloads grandes en memoria critica y no cambies la forma final de Firebase sin actualizar dashboard.

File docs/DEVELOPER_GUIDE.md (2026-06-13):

# SmartGym Developer Guide

Language: English | [Espanol](DEVELOPER_GUIDE.es.md)

## Development Environment

The firmware is a PlatformIO Arduino project for an ESP32-S3 VIEWE display board.

Required environment:

```text
BOARD_VIEWE_UEDX80480070E_WB_A
```

Build:

```powershell
python -m platformio run --environment BOARD_VIEWE_UEDX80480070E_WB_A
```

For local hardware builds, provide private Wi-Fi and Firebase values through PlatformIO build flags or a local untracked config. Do not commit real SSIDs, passwords, Firebase tokens, or private project configuration.

Upload and monitor:

```powershell
python -m platformio run --target upload --target monitor --environment BOARD_VIEWE_UEDX80480070E_WB_A
```

## Repository Layout

The firmware remains at repository root to preserve existing PlatformIO build behavior:

- `src/`: application code.
- `lib/`: firmware modules.
- `boards/`: board configuration.
- `dashboard/`: React dashboard.
- `weight_detection/`: standalone VL53L0X prototype.
- `docs/`: project documentation.
- `hardware/`: wiring notes.
- `screenshots/`: demo images.

## Main Firmware Architecture

`SmartGymTouchApp` is the application orchestrator. It owns the UI state, training state, calibration flow, user sync, Firebase queueing, and memory guards.

Main state categories:

- Idle/Ready.
- Calibration.
- Training.
- Summary.

Main UI screen modes include:

- Main.
- Summary.
- Idle.
- Calibration.
- Calibration gate.
- Debug.
- Profile.

## Main Modules

### SmartGymTouchApp

Coordinates:

- LVGL UI creation and refresh.
- RFID scan flow.
- User profile/calibration sync.
- ROM normalization.
- Rep handling.
- Calibration state machine.
- Session start/finish.
- Firebase upload scheduling.
- Memory-aware upload chunking.

### SensorManager

Reads the analog motion sensor and converts it into a filtered ROM percentage. The firmware configures sampling at 5 ms, approximately 200 Hz.

### RepDetector

Uses a ROM-based state machine:

- Bottom.
- Ascending.
- Top.
- Descending.

It computes rep duration, ROM range, velocities, warnings, and invalid flags.

### SessionRecorder

Stores the active session, sets, reps, per-rep load, timing, ROM, quality metrics, and JSON payloads for Firebase.

Current limits:

- Maximum sets per session: 8.
- Maximum reps per session: 80.

### FirebaseService

Handles Firebase RTDB paths, JSON construction, reads, writes, and FirebaseClient queued transport.

### MachineRegistry

Stores the embedded machine catalog and motion target templates for goals:

- `hypertrophy`
- `strength`
- `endurance`
- `test`

The `test` goal is retained for internal/debug round-trip validation.

### UserRegistry

Stores local user profiles and user-machine calibration data.

Current limits:

- Maximum local profiles: 8.
- Maximum machine calibrations per profile: 8.

### LocalPersistenceStore

Uses NVS/Preferences for:

- Local user cache.
- Local session cache.
- Pending upload queue.

The upload queue is used for retry/offline resilience.

### RfidService

Reads MFRC522 cards and formats UIDs as uppercase hex groups separated by `-`.

## UI Architecture

The firmware uses LVGL. UI refresh is intentionally split into different rates to reduce CPU and memory pressure:

- Main app tick: 4 ms.
- Chart refresh: about 16 ms.
- Slow UI refresh: about 140 ms.
- Debug UI refresh: about 160 ms.

Screen-specific LVGL objects must be reset to `nullptr` when their parent screen/modal is deleted. This prevents stale pointer crashes.

## Calibration Architecture

Calibration is user-specific and machine-type-specific. The flow includes:

- Start load confirmation.
- Physical pin-load controls.
- Rep collection.
- Set analysis.
- Optional next load.
- Result and save.

Calibration records valid/rejected reps, ROM, velocity, load, confidence, action, and recommendation data. Calibration is saved under:

```text
calibrations/{uid}/{machineTypeId}
```

## Recommendation Logic

Recommendation is separate from physical pin load.

- Pin load is machine-level physical state.
- Recommendation is user-specific advice.
- Recommendation must not automatically overwrite pin load.

The firmware resolves recommendation from the latest valid user-machine data, including session summary or calibration data where available.

## Firebase Sync Pipeline

Session finish does not perform heavy Firebase work directly. It schedules a queued upload.

Upload phases:

1. Session root/core.
2. Day metadata.
3. Day timeline.
4. Day summary.
5. Week summary.
6. Representative reps.
7. Set details.
8. Rep sets.

The firmware preserves final Firebase shape while splitting payloads when memory is low.

## Queue and Chunking Behavior

The firmware uses memory modes:

- Normal.
- Constrained.
- Critical.

RepSet upload limits:

- Normal: target 1900 bytes, hard max 2100 bytes, up to 6 reps per patch.
- Constrained: target 900 bytes, hard max 1100 bytes, up to 3 reps per patch.
- Critical: target 650 bytes, hard max 850 bytes, up to 2 reps per patch.

The final Firebase structure remains:

```text
repSets/set1/reps/0
repSets/set1/reps/1
```

No chunk nodes are added to the final schema.

## Adding a New Machine

1. Add a machine seed in `MachineRegistry`.
2. Define machine ID, machine type ID, display name, category, muscles, stroke length, min/max/increment, and default calibration weight.
3. Confirm goal templates and timing targets.
4. Rebuild firmware.
5. Verify Firebase machine config compatibility if cloud overrides are used.

## Editing Goals

Public goals:

- `hypertrophy`
- `strength`
- `endurance`

Internal/debug goal:

- `test`

Legacy compatibility:

- `general`, normalized for new runtime behavior.

Do not remove `test`; it is used for device/Firebase testing.

## Common Serial Log Tags

- `[BOOT]`: startup.
- `[BOOTMEM]`: memory checkpoints.
- `[RFID]`: card scans and user load.
- `[USER_SYNC]`: profile/calibration/recommendation load.
- `[UI_LOADING]`: loading popup.
- `[WEIGHT]`: pin load and recommendation decisions.
- `[SESSION]`: session start, reps, sets, finish.
- `[CAL]`: calibration logic.
- `[CAL_UI]`: calibration screen updates.
- `[SYNC]`: upload and queue behavior.
- `[SYNCGATE]`: cloud sync scheduling.
- `[CloudWrite]`: Firebase writes.
- `[GRAPH]`: graph/timing display.

## Memory Considerations

Firebase/TLS can be memory-sensitive on ESP32. The firmware:

- Frees optional UI before training/upload.
- Uses NVS queueing.
- Limits payload sizes.
- Splits repSet patches under low memory.
- Avoids upload workers.
- Avoids direct heavy upload inside `finishTraining`.

## Known Limitations

- Physical pin load is manual in the main firmware.
- Weight detection is a separate prototype.
- Firebase dashboard config is environment-based; local `.env` files must remain untracked.
- Automated test coverage is limited.

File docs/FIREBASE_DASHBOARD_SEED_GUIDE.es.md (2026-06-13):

# Guia De Seed Firebase Para Dashboard

Idioma: [English](FIREBASE_DASHBOARD_SEED_GUIDE.md) | Espanol

Este documento explica el archivo grande de datos de ejemplo para probar el dashboard:

- `sample_data/firebase_rtdb_dashboard_seed_2026_w12_w17.json`

El archivo fue generado por:

- `tools/generate_dashboard_seed.py`

## Proposito

Este seed no es solo una demo pequena. Sirve para validar un dashboard SmartGym completo con datos sinteticos pero realistas.

Incluye suficiente informacion para probar:

- lista de usuarios
- estado actual del dispositivo
- vistas semanales y diarias
- progreso por maquina
- detalle de sets y repeticiones
- tendencias de metricas corporales
- retroalimentacion post-sesion como `RPE` y notas

## Tamano Del Dataset

Dataset generado actualmente:

- `5` usuarios
- `5` maquinas
- `6` semanas
- `147` dias de entrenamiento
- `673` sesiones de maquina

Cada usuario entrena aproximadamente `4-6` dias por semana. Cada dia de entrenamiento contiene `4-5` sesiones de maquina.

## Nodos Principales

El seed contiene estos nodos principales:

- `usersByRfid`
- `calibrations`
- `calibrationHistory`
- `machineConfigs`
- `devices`
- `bodyMetricsHistory`
- `sessionFeedback`
- `athleteWeeklySessions`

## Que Significa Cada Nodo

### `usersByRfid`

Tabla de perfiles de atletas. Cada usuario incluye:

- UID RFID
- nombre visible
- datos corporales
- meta principal

Se usa para el selector de atleta, encabezado de perfil y filtros por objetivo.

### `calibrations`

Calibracion efectiva por usuario y tipo de maquina. Cada registro puede contener:

- `suggestedWeightKg`
- `userRomPercent`
- `hasCalibration`

Se usa para revisar si el usuario ya calibro, mostrar carga recomendada y guiar el flujo de preparacion de maquina.

### `calibrationHistory`

Historial de eventos de calibracion. Sirve para:

- graficas de tendencia
- revisar cambios de carga sugerida
- auditar recalibraciones

### `machineConfigs`

Metadata de las maquinas y fuente de recomendaciones base. Cada maquina incluye:

- IDs de maquina
- valores ROM default
- peso default de calibracion
- recomendaciones por meta
- campos de configuracion del encoder
- taxonomia:
  - `exerciseCategory`
  - `primaryMuscleGroup`
  - `secondaryMuscleGroup`

Se usa para tarjetas de maquina, agrupacion por ejercicio, dashboards musculares y pantallas administrativas.

### `devices`

Estado vivo de los dispositivos ESP32. Cada dispositivo puede incluir:

- identidad del dispositivo
- maquina asignada
- usuario activo
- estado de la app
- estado Wi-Fi
- estado de calibracion del encoder

Se usa para monitoreo en piso, diagnostico y para saber que maquina esta activa.

### `bodyMetricsHistory`

Historial de check-in corporal manejado por la web app. Cada fecha puede contener:

- peso corporal
- porcentaje de grasa
- porcentaje de musculo esqueletico
- cintura
- sueno
- energia
- notas

### `sessionFeedback`

Retroalimentacion subjetiva post-entrenamiento. Puede contener:

- `rpe`
- `energyScore`
- `sorenessScore`
- `painScore`
- `readinessScore`
- `notes`

Se usa para pantallas de revision de sesion, notas de entrenador y comparacion entre datos objetivos y subjetivos.

### `athleteWeeklySessions`

Arbol principal del historial de entrenamiento.

Forma de ruta:

```text
athleteWeeklySessions/{uid}/{weekKey}/days/{dayKey}
```

Dentro de cada dia existen:

- `meta`
- `daySummary`
- `timeline`
- `sessions`

## Estructura De Una Sesion

Cada sesion de maquina vive en:

```text
athleteWeeklySessions/{uid}/{weekKey}/days/{dayKey}/sessions/{sessionId}
```

Una sesion incluye:

- `identity`
- `machine`
- `timing`
- `plan`
- `summary`
- `analysis`
- `setOverview`
- `setDetails`
- `repSets`
- `representativeReps`

### `summary`

Bloque rapido de resultado de sesion. Ejemplos:

- `setsCompleted`
- `validReps`
- `invalidReps`
- `volumeLoadKg`
- `avgRomPercent`
- `avgPeakVelocityPctPerSec`

### `analysis`

Bloque mas rico para dashboard y coaching. Ejemplos:

- `romComplianceRate`
- `idealRomHitRate`
- `avgRestSecondsPerSet`
- `fatigueRomDrop`
- `fatigueVelocityDrop`
- contadores de razones invalidas

### `setOverview`

Resumen por set. Se puede usar para tarjetas rapidas, comparacion de fatiga y revision de entrenador.

### `setDetails`

Objeto mas explicito set por set. Se usa para tablas o vistas de analisis mas profundas.

### `repSets`

Detalle de repeticiones agrupado por set. Cada repeticion puede incluir:

- validez
- ROM
- duracion
- tiempo concentrico
- velocidad concentrica pico
- velocidad excentrica pico
- banderas de advertencia

Esta forma debe mantenerse compatible con lo que escribe el firmware.

## Como Se Construyo El Seed

El generador crea uso sintetico de gimnasio con reglas simples:

- los usuarios entrenan `4-6` veces por semana
- cada dia usa `4-5` maquinas
- las sesiones varian por meta, maquina y calibracion
- algunas repeticiones son validas y otras invalidas
- algunas sesiones tienen fatiga o advertencias
- metricas corporales y feedback estan separados de los datos del dispositivo

El seed es bueno para probar UI, filtros y graficas. No debe interpretarse como un modelo fisiologico exacto.

## Mejor Forma De Explorarlo

Para entender el archivo rapido, revisalo en este orden:

1. `usersByRfid`
2. `machineConfigs`
3. un usuario dentro de `athleteWeeklySessions`
4. una semana
5. un dia
6. una sesion
7. `summary`, `analysis`, `setDetails` y `repSets` de esa sesion

Ese recorrido da el modelo mental completo sin leer todo el JSON.

## Pruebas Recomendadas Para Dashboard

Este seed sirve especialmente para validar:

1. graficas de actividad semanal
2. resumenes de sesiones y volumen
3. filtros por maquina y grupo muscular
4. tendencias de metricas corporales
5. paginas de detalle con analisis de repeticiones
6. paneles de revision con `RPE` y notas
7. monitoreo de dispositivos usando `devices`

## Regenerar El Seed

Desde la raiz del repositorio:

```powershell
@'
import runpy
runpy.run_path('tools/generate_dashboard_seed.py', run_name='__main__')
'@ | python -
```

El archivo de salida se reescribe en:

- `sample_data/firebase_rtdb_dashboard_seed_2026_w12_w17.json`

## Uso Seguro

No importes este seed en la raiz de una base real si no quieres reemplazar datos. Usalo en una base de pruebas o importa solo nodos especificos.

Orden recomendado:

1. Crear un proyecto/base de prueba.
2. Importar el seed completo solo en ambiente demo.
3. Ejecutar el dashboard.
4. Confirmar usuarios, semanas, sesiones, graficas y detalles.
5. No mezclarlo con datos reales de usuarios.

## Nota Importante

Este seed contiene datos de dos dominios:

- datos propiedad del firmware:
  - maquinas
  - sesiones
  - calibraciones
  - dispositivos
- datos propiedad de la web app:
  - `bodyMetricsHistory`
  - `sessionFeedback`

La separacion es intencional. Permite validar el flujo completo del producto, no solo la subida de datos del ESP32.

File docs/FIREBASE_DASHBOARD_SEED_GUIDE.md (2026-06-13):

# Firebase Dashboard Seed Guide

Language: English | [Espanol](FIREBASE_DASHBOARD_SEED_GUIDE.es.md)

This document explains the large dashboard seed file:

- [firebase_rtdb_dashboard_seed_2026_w12_w17.json](C:/Users/chomp/OneDrive/Viejo/Documentos/PlatformIO/Projects/SmartGym_DisplayBringup/sample_data/firebase_rtdb_dashboard_seed_2026_w12_w17.json)

It was generated by:

- [generate_dashboard_seed.py](C:/Users/chomp/OneDrive/Viejo/Documentos/PlatformIO/Projects/SmartGym_DisplayBringup/tools/generate_dashboard_seed.py)

## Purpose

This seed is meant to validate a full SmartGym dashboard, not just a simple demo.

It includes enough data to test:

- user list screens
- current device status
- weekly and daily activity views
- machine-specific progress
- rep and set detail pages
- body metric trends
- post-session feedback like `RPE` and notes

## Dataset Size

Current generated dataset:

- `5` users
- `5` machines
- `6` weeks
- `147` training days
- `673` machine sessions

Each user trains roughly `4-6` days per week.

Each training day contains `4-5` machine sessions.

## Top-Level Nodes

The seed contains these main roots:

- `usersByRfid`
- `calibrations`
- `calibrationHistory`
- `machineConfigs`
- `devices`
- `bodyMetricsHistory`
- `sessionFeedback`
- `athleteWeeklySessions`

## What Each Root Means

### `usersByRfid`

This is the athlete profile table.

Each user has:

- RFID UID
- display name
- body stats
- primary goal

Use this for:

- athlete selector
- profile header
- goal-based filtering

### `calibrations`

This is the current effective calibration per user and machine type.

Each record contains:

- `suggestedWeightKg`
- `userRomPercent`
- `hasCalibration`

Use this for:

- readiness checks
- showing recommended weight
- machine onboarding logic

### `calibrationHistory`

This is the historical calibration log.

Use this for:

- calibration trend charts
- seeing if suggested weight changed over time
- auditing recalibration events

### `machineConfigs`

This is the machine metadata and recommendation source.

Each machine contains:

- machine IDs
- ROM defaults
- default calibration weight
- goal recommendations
- encoder config fields
- taxonomy fields:
  - `exerciseCategory`
  - `primaryMuscleGroup`
  - `secondaryMuscleGroup`

Use this for:

- machine cards
- exercise grouping
- muscle group dashboards
- settings/admin screens

### `devices`

This is the live device state table.

Each device contains:

- device identity
- assigned machine
- active user UID
- app state
- wifi state
- encoder calibration state

Use this for:

- live gym-floor monitor
- “which machine is active right now?”
- device diagnostics

### `bodyMetricsHistory`

This is web-app-owned athlete check-in history.

Each date entry may contain:

- weight
- body fat
- skeletal muscle percentage
- waist
- sleep
- energy score
- notes

Use this for:

- transformation tracking
- bodyweight charts
- recovery dashboards

### `sessionFeedback`

This is web-app-owned post-workout feedback.

Each session may contain:

- `rpe`
- `energyScore`
- `sorenessScore`
- `painScore`
- `readinessScore`
- `notes`

Use this for:

- session review screens
- coach notes overlays
- combining objective and subjective progress

### `athleteWeeklySessions`

This is the main workout history tree.

Path shape:

```text
athleteWeeklySessions/{uid}/{weekKey}/days/{dayKey}
```

Inside each day:

- `meta`
- `daySummary`
- `timeline`
- `sessions`

Use this for:

- weekly dashboard
- day timeline
- full session analysis

## Session Structure

Each machine session lives here:

```text
athleteWeeklySessions/{uid}/{weekKey}/days/{dayKey}/sessions/{sessionId}
```

A session includes:

- `identity`
- `machine`
- `timing`
- `plan`
- `summary`
- `analysis`
- `setOverview`
- `setDetails`
- `repSets`
- `representativeReps`

### `summary`

This is the fast session result block.

Examples of fields:

- `setsCompleted`
- `validReps`
- `invalidReps`
- `volumeLoadKg`
- `avgRomPercent`
- `avgPeakVelocityPctPerSec`

### `analysis`

This is the richer dashboard/coaching block.

Examples of fields:

- `romComplianceRate`
- `idealRomHitRate`
- `avgRestSecondsPerSet`
- `fatigueRomDrop`
- `fatigueVelocityDrop`
- invalid reason counters

### `setOverview`

This is the per-set summary array.

Use it for:

- set cards
- fatigue comparison
- quick coach review

### `setDetails`

This is a more explicit set-by-set object.

Use it for:

- set tables
- deeper analysis views

### `repSets`

This is the rep-level detail grouped by set.

Each rep can include:

- validity
- ROM
- duration
- concentric time
- peak concentric velocity
- peak eccentric velocity
- warning flags

Use it for:

- motion charts
- rep scatter plots
- coaching detail pages

## How The Seed Was Built

The generator creates realistic but synthetic gym usage.

Main rules:

- users train `4-6` times per week
- each training day uses `4-5` machines
- sessions vary by goal, machine, and calibration
- reps include valid and invalid attempts
- some sessions include fatigue and warning patterns
- body metrics and feedback are included separately from device data

This means the seed is good for UI testing, filtering, and chart validation, but
it is still synthetic data, not a physiological model.

## Best Ways To Explore It

If you want to understand the file quickly, inspect it in this order:

1. `usersByRfid`
2. `machineConfigs`
3. one user under `athleteWeeklySessions`
4. one week
5. one day
6. one session
7. that session’s `summary`, `analysis`, `setDetails`, and `repSets`

That path gives you the whole mental model without needing to read the entire
file.

## Recommended Dashboard Tests

This seed is especially useful to validate:

1. Weekly activity charts
2. Session count and volume summaries
3. Machine filtering by type and muscle group
4. Body metrics trend charts
5. Session detail pages with rep analysis
6. Coach review panels using `RPE` and notes
7. Device-monitor screens using `devices`

## Regenerating The Seed

To regenerate the seed:

```powershell
@'
import runpy
runpy.run_path('tools/generate_dashboard_seed.py', run_name='__main__')
'@ | python -
```

The output file will be rewritten at:

- [firebase_rtdb_dashboard_seed_2026_w12_w17.json](C:/Users/chomp/OneDrive/Viejo/Documentos/PlatformIO/Projects/SmartGym_DisplayBringup/sample_data/firebase_rtdb_dashboard_seed_2026_w12_w17.json)

## Important Note

This seed contains both:

- firmware-owned data
  - machine taxonomy
  - sessions
  - calibrations
  - devices
- web-app-owned data
  - `bodyMetricsHistory`
  - `sessionFeedback`

That split is intentional so your dashboard can validate the complete product
flow, not only the embedded device upload.

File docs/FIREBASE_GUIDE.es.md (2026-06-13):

# Guia De Firebase SmartGym

Idioma: [English](FIREBASE_GUIDE.md) | Espanol

SmartGym usa Firebase Realtime Database para perfiles, calibraciones, historial de sesiones, resumenes, graficas de dashboard y heartbeat del dispositivo.

## Advertencia De Seguridad

No importes un JSON completo en la raiz de Firebase salvo que quieras reemplazar toda la base.

No commitees secretos, service accounts, tokens privados, contrasenas Wi-Fi ni `.env`. La configuracion web publica tambien debe restringirse con reglas Firebase y restricciones de dominio/app.

Patron de importacion seguro:

- Importar usuarios en `usersByRfid`.
- Importar calibraciones en `calibrations`.
- Importar configuracion de maquinas en `machineConfigs`.
- Importar sesiones en `athleteWeeklySessions/{uid}/{weekKey}`.

## Nodos Principales RTDB

### usersByRfid

```text
usersByRfid/{uid}
```

Guarda perfil asociado a RFID: nombre, edad, altura, peso, genero y meta preferida.

### calibrations

```text
calibrations/{uid}/{machineTypeId}
```

Guarda:

- bandera de calibracion
- carga sugerida/recomendada
- bottom/top/rango ROM
- confianza
- accion
- razon
- recomendaciones por meta
- snapshot de motion target
- sets de calibracion
- next recommended weight

### machineConfigs

```text
machineConfigs/{machineId}
```

Configuracion cloud de maquina cuando existe. El firmware tambien incluye un catalogo embebido para poder arrancar offline.

### athleteWeeklySessions

```text
athleteWeeklySessions/{uid}/{weekKey}
```

Nodo principal de historial.

Estructura tipica:

```text
athleteWeeklySessions/{uid}/{weekKey}/days/{dayKey}/sessions/{sessionId}
athleteWeeklySessions/{uid}/{weekKey}/days/{dayKey}/daySummary
athleteWeeklySessions/{uid}/{weekKey}/days/{dayKey}/timeline/{timelineKey}
athleteWeeklySessions/{uid}/{weekKey}/weekSummary
```

### devices

```text
devices/{deviceId}
```

Guarda heartbeat e identidad/estado del dispositivo.

## Raiz De Sesion

Incluye:

- ID de sesion.
- UID de usuario.
- Maquina y tipo.
- Meta.
- Inicio/fin.
- Duracion.
- Pin load.
- Carga recomendada.
- Totales de reps/sets.
- Reps validas/invalidas.
- Metricas ROM y velocidad.
- Calidad.
- Links a detalles pesados.

## daySummary

Resumen diario para lecturas rapidas del dashboard.

## weekSummary

Resumen semanal del usuario/semana activa.

## timeline

Entradas ligeras ordenadas para tarjetas del dashboard. Tambien funcionan como marcador de idempotencia para evitar duplicados en reintentos.

## representativeReps

Guarda reps seleccionadas:

- Mejor ROM.
- Mejor velocidad.
- Primera valida.
- Ultima valida.

## setDetails

Guarda resumen por set:

- numero de set
- reps objetivo
- reps validas
- reps invalidas
- carga inicio/fin
- si cambio peso
- resumen ROM/velocidad

## repSets

Guarda datos profundos por rep:

```text
repSets/set1/reps/0
repSets/set1/reps/1
```

El firmware puede subirlos en PATCH pequenos, pero la forma final en Firebase no cambia.

## Fases De Subida

1. Root/core de sesion.
2. Metadata diaria.
3. Timeline.
4. Day summary.
5. Week summary.
6. Representative reps.
7. Set details.
8. Rep sets.

## Subida Segura En Memoria

El firmware usa cola NVS y fragmentacion segun memoria. Con heap restringido, repSets se dividen en patches pequenos para evitar bloqueos Firebase/TLS.

## Compatibilidad Dashboard

El dashboard lee:

- `usersByRfid/{rfid}`
- `athleteWeeklySessions/{rfid}`
- `athleteWeeklySessions/{rfid}/{week}/days`
- `recommendedRoutineProgress/{rfid}/{selectedDate}`

No renombres rutas del firmware sin actualizar el dashboard.

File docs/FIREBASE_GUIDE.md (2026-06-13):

# SmartGym Firebase Guide

Language: English | [Espanol](FIREBASE_GUIDE.es.md)

SmartGym uses Firebase Realtime Database as the backend for user profiles, calibration data, session history, summaries, dashboard charts, and device heartbeat.

## Safety Warning

Do not import a full JSON file at the Firebase root unless you intentionally want to replace the entire database.

Do not commit database secrets, service account files, private auth tokens, Wi-Fi passwords, or local `.env` files. Public Firebase web config should still be restricted with proper Firebase rules and domain/app restrictions.

Safer import pattern:

- Import user JSON at `usersByRfid`.
- Import calibration JSON at `calibrations`.
- Import machine config JSON at `machineConfigs`.
- Import session data at the matching `athleteWeeklySessions/{uid}/{weekKey}` node.

## Main RTDB Nodes

### usersByRfid

```text
usersByRfid/{uid}
```

Stores RFID-linked user profile data such as display name, age, height, weight, gender, and preferred goal.

Profile reads happen during RFID user sync. Profile writes should only happen for explicit profile edits or intentional compatibility fields.

### calibrations

```text
calibrations/{uid}/{machineTypeId}
```

Stores user-machine calibration data:

- Has calibration flag.
- Suggested/recommended load.
- User ROM bottom/top/range.
- Confidence.
- Action.
- Reason.
- Goal-specific recommendations.
- Motion target snapshot.
- Calibration set snapshots.
- Next recommended weight fields.

### machineConfigs

```text
machineConfigs/{machineId}
```

Stores cloud machine configuration where available. The firmware also contains an embedded machine catalog so it can boot offline.

### athleteWeeklySessions

```text
athleteWeeklySessions/{uid}/{weekKey}
```

This is the main workout history node for dashboard analysis.

Typical structure:

```text
athleteWeeklySessions/{uid}/{weekKey}/days/{dayKey}/sessions/{sessionId}
athleteWeeklySessions/{uid}/{weekKey}/days/{dayKey}/daySummary
athleteWeeklySessions/{uid}/{weekKey}/days/{dayKey}/timeline/{timelineKey}
athleteWeeklySessions/{uid}/{weekKey}/weekSummary
```

### devices

```text
devices/{deviceId}
```

Stores heartbeat and device identity/status data.

## Session Root

The session root contains the main record for a completed workout:

- Session ID.
- User UID.
- Machine ID/type.
- Goal.
- Started/ended time.
- Duration.
- Selected/pin load.
- Recommended load.
- Set/repetition totals.
- Valid/invalid rep counts.
- ROM and velocity metrics.
- Quality score/tier.
- Links to heavy details.

## daySummary

Daily aggregate summary for fast dashboard reads. It avoids requiring the dashboard to scan every session for common day-level metrics.

## weekSummary

Weekly aggregate summary for the active user/week. It includes summary counters and recent training signal information.

## timeline

Timeline entries are lightweight ordered cards for the dashboard. The timeline key also acts as an idempotency marker so retries do not double-count summaries.

## representativeReps

Stores selected representative reps, such as:

- Best ROM rep.
- Best velocity rep.
- First valid rep.
- Last valid rep.

## setDetails

Stores per-set summary information:

- Set number.
- Target reps.
- Valid reps.
- Invalid reps.
- Start/end selected load.
- Whether weight changed during set.
- ROM/velocity summaries.

## repSets

Stores deeper per-rep data by set:

```text
repSets/set1/reps/0
repSets/set1/reps/1
```

The firmware may upload these details in smaller PATCH payloads, but the final Firebase shape remains unchanged.

## Upload Phases

1. Root session/core data.
2. Day metadata.
3. Timeline.
4. Day summary.
5. Week summary.
6. Representative reps.
7. Set details.
8. Rep sets.

## Memory-Safe Upload

The firmware uses NVS queueing and memory-aware payload splitting. Under constrained heap, repSets are split into smaller patches to avoid Firebase/TLS blocking.

## Dashboard Compatibility

The dashboard currently reads:

- `usersByRfid/{rfid}`
- `athleteWeeklySessions/{rfid}`
- `athleteWeeklySessions/{rfid}/{week}/days`
- `recommendedRoutineProgress/{rfid}/{selectedDate}`

Do not rename the firmware paths without updating the dashboard.

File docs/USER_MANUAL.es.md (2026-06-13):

# Manual de Usuario SmartGym

Idioma: [English](USER_MANUAL.md) | Espanol

Este manual explica como usar el sistema SmartGym Adaptive Training como evaluador, atleta o usuario de demo.

## 1. Encender El Dispositivo

1. Conecta energia a la pantalla ESP32-S3.
2. Espera a que aparezca la pantalla principal.
3. Permite que el dispositivo conecte Wi-Fi, Firebase, RFID y servicios de tiempo.
4. No inicies un entrenamiento hasta que el dispositivo llegue al estado listo.

## 2. Login Por RFID

1. Acerca la tarjeta RFID al lector.
2. La pantalla muestra un popup de carga.
3. Espera hasta que el popup se cierre.

El popup permanece visible mientras el dispositivo carga:

- Perfil de usuario.
- Calibracion del usuario para la maquina activa.
- Recomendacion para usuario y maquina activos.
- Mapeo ROM calibrado.

No se debe presionar START o CALIBRATE mientras el popup de carga esta activo.

## 3. Pantalla Principal

La pantalla principal muestra estado de sesion, grafica de movimiento, carga de pin, recomendacion, repeticiones, series y botones de accion.

Terminos importantes:

- Pin load: posicion fisica del pin de peso en la maquina.
- Recommended load: carga sugerida por SmartGym para el usuario activo.

La carga de pin pertenece a la maquina, no al usuario. No cambia automaticamente cuando otro usuario escanea RFID. La recomendacion es consejo especifico para el usuario.

## 4. Pin Load Vs Recommended Load

El sistema nunca mueve fisicamente el pin de peso. Si la pantalla recomienda 25.0 kg pero la maquina esta en 20.0 kg, el dispositivo muestra ambos valores:

- Pin load: 20.0 kg
- Recommended: 25.0 kg

Si el usuario quiere seguir la recomendacion, debe mover fisicamente el pin y actualizar el valor mostrado con los botones tactiles.

## 5. Cambiar Pin Load

Usa los cuatro botones de peso:

- `-5`
- `-2.5`
- `+2.5`
- `+5`

Estos botones actualizan la carga de pin mostrada. No cambian la recomendacion.

El pin load puede cambiar antes o durante el entrenamiento. Si cambia durante el entrenamiento, las repeticiones posteriores se registran con la nueva carga.

## 6. Iniciar Un Entrenamiento

1. Escanea RFID y espera a que termine la carga.
2. Revisa el pin load.
3. Ajusta fisicamente el pin de la maquina si hace falta.
4. Ajusta el pin load en pantalla para que coincida con el pin fisico.
5. Presiona START.

La sesion inicia usando exactamente el pin load mostrado.

## 7. Seguir La Grafica

La grafica muestra el movimiento a traves del rango del ejercicio. El firmware usa ROM, o rango de movimiento, para detectar repeticiones.

Las pistas para usuario se enfocan en tiempo:

- Tiempo de subida.
- Tiempo de bajada.
- Pausa arriba.
- Pausa abajo.

La interfaz principal evita mostrar valores tecnicos crudos como `%ROM/s`.

## 8. Repeticiones Y Series

El firmware detecta repeticiones desde la senal ROM. Una repeticion debe moverse por suficiente rango y pasar reglas internas de validacion.

La pantalla muestra:

- Repeticiones actuales en la serie.
- Serie actual.
- Estado de entrenamiento.
- Timer o progreso cuando esta disponible.

Si una repeticion no cuenta, las causas pueden ser ROM corto, movimiento ruidoso o no llegar a umbrales de arriba/abajo.

## 9. Descanso Y Finalizacion

Cuando se completan las repeticiones objetivo de una serie, el sistema marca la serie como completa. Segun el numero objetivo de series, la sesion puede terminar automaticamente o continuar a la siguiente serie.

El usuario tambien puede terminar manualmente presionando FINISH.

## 10. Resumen Y Sync

Despues de terminar, aparece la pantalla de resumen. Puede mostrar:

- Sesion completa.
- Pin load usado.
- Nueva recomendacion.
- Estado de guardado/subida.

Estados tipicos:

- Saving session...
- Uploading core...
- Uploading details...
- Uploading reps...
- Session saved.
- Saving in background.

Si la sincronizacion sigue corriendo, el dispositivo puede guardar en segundo plano. No se debe apagar inmediatamente despues de entrenar si la pantalla aun indica guardado.

## 11. Calibracion

Usa calibracion cuando:

- Un usuario nuevo use la maquina.
- El ROM se vea incorrecto.
- Falten recomendaciones.
- El sistema indique calibrate first.
- Cambie la configuracion del ejercicio.

## Pasos De Calibracion

1. Presiona CALIBRATE.
2. Lee el titulo e instruccion del paso.
3. Mueve el pin fisico a la carga sugerida si aplica.
4. Usa los cuatro botones de pin load si el valor en pantalla no coincide con el pin fisico.
5. Toca LOAD SET.
6. Haz 3 a 5 repeticiones suaves.
7. Sigue cualquier instruccion de siguiente carga.
8. Guarda el resultado al terminar.

La pantalla de calibracion muestra:

- Pin load.
- Carga sugerida.
- Botones de ajuste de peso.
- Feedback de repeticiones.
- Acciones de guardar/cancelar.

Si el pin load difiere de la carga sugerida, el usuario puede continuar, pero el dispositivo registra que se eligio un pin fisico distinto.

## 12. Recomendaciones

Las recomendaciones se generan desde calibracion e historial de sesiones. Son consejo solamente. El sistema no cambia automaticamente el pin fisico.

Fuentes posibles:

- Calibracion.
- Ultima sesion.
- Default de maquina.
- Sin recomendacion.

## 13. Troubleshooting Rapido

### RFID No Detectado

- Acerca mas la tarjeta al lector.
- Espera a que termine upload/sync.
- Intenta escanear de nuevo.

### Usuario Sigue Cargando

- Espera a que cierre el popup.
- Si falla la lectura cloud, el dispositivo debe hacer fallback seguro.

### Repeticion No Contada

- Usa ROM completo.
- Muevete suavemente.
- Llega a posiciones de arriba y abajo.
- Recalibra si el mapeo ROM se ve mal.

### Grafica Incorrecta

- Recalibra ROM.
- Revisa conexion del sensor de movimiento.
- Confirma que no cambio la configuracion de la maquina.

### Sync Sigue Corriendo

- Mantén el dispositivo encendido.
- Espera "Session saved" si es posible.
- El dispositivo puede seguir guardando en segundo plano.

### Recomendacion No Cambia Pin Load

Esto es esperado. Pin load es el estado fisico de la maquina. El usuario debe mover el pin y actualizar pantalla manualmente.

### Wi-Fi O Firebase

- Revisa credenciales Wi-Fi.
- Revisa URL/configuracion de Firebase RTDB.
- Confirma conectividad a internet.
- Usa logs seriales para detalles.

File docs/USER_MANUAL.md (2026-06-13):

# SmartGym User Manual

Language: English | [Espanol](USER_MANUAL.es.md)

This manual explains how to use the SmartGym Adaptive Training System as an evaluator, athlete, or demo user.

## 1. Turning On the Device

1. Connect power to the ESP32-S3 display.
2. Wait for the main screen to appear.
3. Allow the device to connect to Wi-Fi, Firebase, RFID, and time services.
4. Do not start a workout until the device reaches the ready state.

## 2. RFID Login

1. Place the RFID card near the reader.
2. The screen shows a loading popup.
3. Keep waiting until the popup closes.

The popup remains visible while the device loads:

- User profile.
- User calibration for the active machine.
- Recommendation for the active user and machine.
- Calibrated ROM mapping.

The user should not press START or CALIBRATE while the loading popup is active.

## 3. Main Screen

The main screen shows the current session state, live motion graph, pin load, recommendation, reps, sets, and action buttons.

Important terms:

- Pin load: the physical weight pin position on the machine.
- Recommended load: the load suggested by SmartGym for the active user.

The pin load belongs to the machine, not the user. It does not automatically change when a different user scans an RFID card. The recommendation is user-specific advice.

## 4. Pin Load vs Recommended Load

The system never physically moves the weight pin. If the screen recommends 25.0 kg but the machine pin is at 20.0 kg, the device shows both values separately:

- Pin load: 20.0 kg
- Recommended: 25.0 kg

If the user wants to follow the recommendation, they must physically move the pin and then update the displayed pin load with the touchscreen buttons.

## 5. Changing Pin Load

Use the four weight buttons:

- `-5`
- `-2.5`
- `+2.5`
- `+5`

These buttons update the displayed machine pin load. They do not change the recommendation.

Pin load can be changed before training or during training. If it changes during training, later reps are recorded with the new load.

## 6. Starting a Workout

1. Scan RFID and wait for loading to finish.
2. Check the pin load.
3. Physically set the machine pin if needed.
4. Adjust the on-screen pin load to match the physical pin.
5. Press START.

The session starts using the displayed pin load exactly as shown.

## 7. Following the Graph

The graph shows motion through the exercise range. The firmware uses ROM, or range of motion, to detect repetitions.

The user-facing cues focus on timing, for example:

- Rise time.
- Lower time.
- Top hold.
- Bottom hold.

The system avoids showing raw technical values such as `%ROM/s` in the main user interface.

## 8. Reps and Sets

The firmware detects reps from the ROM signal. A rep must move through enough range and pass the internal validation rules.

The screen shows:

- Current reps in the set.
- Current set.
- Training state.
- Timer or progress where available.

If a rep is not counted, possible causes include short range of motion, noisy movement, or not reaching the top/bottom thresholds.

## 9. Rest and Finishing

When the target reps for a set are completed, the system marks the set complete. Depending on the target set count, the session may auto-finish or continue to the next set.

The user can also finish manually by pressing FINISH.

## 10. Summary Screen and Sync

After finishing, the summary screen appears. It may show:

- Session complete.
- Pin load used.
- New recommendation.
- Save/upload status.

Typical save states:

- Saving session...
- Uploading core...
- Uploading details...
- Uploading reps...
- Session saved.
- Saving in background.

If sync is still running, the device can continue saving in the background. Do not power off immediately after a workout if the screen still indicates saving.

## 11. Calibration

Calibration should be used when:

- A new user uses the machine.
- ROM looks incorrect.
- Recommendations are missing.
- The system says to calibrate first.
- The exercise setup has changed.

### Calibration Steps

1. Press CALIBRATE.
2. Read the step title and instruction.
3. Move the physical pin to the suggested load if appropriate.
4. Use the calibration screen's four pin-load buttons if the displayed pin does not match the physical pin.
5. Tap LOAD SET.
6. Perform 3 to 5 smooth reps.
7. Follow any next-load instruction.
8. Save the result when complete.

The calibration screen shows:

- Pin load.
- Suggested load.
- Weight adjustment buttons.
- Rep feedback.
- Save/cancel actions.

If the pin load differs from the suggested load, the user may still continue, but the device logs that the user chose a different physical pin.

## 12. Recommendations

Recommendations are generated from calibration and session history. They are advice only. The system does not automatically change the physical pin load.

Recommendation sources may include:

- Calibration.
- Last session.
- Machine default.
- No recommendation.

## 13. Troubleshooting

### RFID Not Detected

- Hold the card closer to the RFID reader.
- Wait for upload/sync to finish.
- Try scanning again.

### User Still Loading

- Wait for the loading popup to close.
- If cloud read fails, the device should fall back safely.

### Rep Not Counted

- Use full range of motion.
- Move smoothly.
- Reach the top and bottom positions.
- Recalibrate if ROM mapping looks wrong.

### Graph Looks Wrong

- Recalibrate ROM.
- Check the motion sensor connection.
- Confirm the exercise machine setup did not change.

### Sync Still Running

- Keep the device powered.
- Wait for "Session saved" if possible.
- The device may continue saving in the background.

### Recommendation Does Not Change Pin Load

This is expected. The pin load is the physical machine state. The user must move the pin and update the display manually.

### Wi-Fi or Firebase Issues

- Check Wi-Fi credentials.
- Check Firebase RTDB URL/auth configuration.
- Confirm internet connectivity.
- Use serial logs for details.

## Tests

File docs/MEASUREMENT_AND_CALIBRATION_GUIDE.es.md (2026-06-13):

# Guia De Medicion Y Calibracion SmartGym

Idioma: [English](MEASUREMENT_AND_CALIBRATION_GUIDE.md) | Espanol

Esta guia explica como SmartGym mide movimiento, convierte lecturas de sensor en valores utiles, calibra ROM, maneja carga de pin y detecta errores comunes. Esta escrita para alguien que no construyo el proyecto y necesita entenderlo de extremo a extremo.

## Proposito

Durante un entrenamiento, el firmware debe responder:

- Donde esta la maquina en su recorrido.
- Si el usuario esta subiendo o bajando.
- Si acaba de ocurrir una repeticion valida.
- Que carga fisica tenia la maquina.
- Que recomendacion debe mostrarse despues.

Para eso, SmartGym combina:

- Sensor analogico de movimiento.
- Calibracion ROM especifica por usuario.
- Maquina de estados para repeticiones.
- Modelo de carga de pin de maquina.
- Registro local de sesion.
- Sincronizacion con Firebase.

## Vista General

El pipeline de medicion es:

1. Muestrear el sensor analogico cada 5 ms.
2. Suavizar la lectura con filtro EMA.
3. Convertir la lectura filtrada en posicion de maquina.
4. Normalizar la posicion a porcentaje ROM usando bottom/top calibrados.
5. Calcular velocidad desde el cambio de posicion normalizada.
6. Ejecutar la maquina de estados de repeticion.
7. Registrar reps, series, tiempos, pin load y metricas.
8. Guardar la sesion localmente y subirla a Firebase por fases.

## Entradas De Sensor

### Sensor De Movimiento

El firmware principal usa un sensor analogico conectado a GPIO 17 en el ESP32-S3. La lectura se realiza cada 5 ms:

```text
sample_interval = 0.005 s
sample_rate = 1 / 0.005 = 200 Hz
```

Esta frecuencia permite resolver movimiento normal de gimnasio mientras el ESP32-S3 tambien ejecuta LVGL y Firebase.

### RFID

RFID identifica al usuario activo. El firmware necesita el usuario para cargar calibracion ROM y recomendacion correctas.

### Pin Load

El firmware trata el pin load como estado de la maquina, no del usuario. En el firmware principal, el usuario actualiza el valor con botones de pantalla. La carpeta `weight_detection/` contiene un prototipo VL53L0X separado para deteccion automatica del stack.

## De Senal Cruda A Posicion

El ADC del ESP32-S3 es de 12 bits, con rango:

```text
0 a 4095 counts
```

Si el recorrido completo se modela como 2000 mm, la resolucion teorica es:

```text
resolution_mm = 2000 / 4096 = 0.488 mm por count
```

Un modelo conceptual de conversion es:

```text
position_mm = (adc_or_voltage / full_scale) * stroke_length_mm
```

Donde:

- `position_mm` es la posicion estimada.
- `adc_or_voltage` es la senal medida.
- `full_scale` es la referencia de escala completa.
- `stroke_length_mm` es el recorrido asumido.

## Filtrado

La senal se suaviza con un promedio movil exponencial:

```text
filtered[k] = alpha * raw[k] + (1 - alpha) * filtered[k - 1]
```

Con un valor alrededor de:

```text
alpha = 0.50
```

El filtro reduce ruido ADC, vibracion mecanica y cambios falsos de pendiente. Demasiado poco filtrado genera reps falsas; demasiado filtrado introduce retraso.

## Calibracion ROM

La calibracion es especifica por usuario y tipo de maquina. Guarda un punto inferior y superior.

Flujo:

1. Mover a posicion inferior y confirmar.
2. Mover a posicion superior y confirmar.
3. Confirmar pin load actual.
4. Hacer repeticiones controladas.
5. Guardar resultado y recomendacion.

## Normalizacion ROM

Con bottom y top, el firmware calcula:

```text
rom_percent = ((x - x_bottom) / (x_top - x_bottom)) * 100
```

Donde:

- `x` es la posicion actual filtrada.
- `x_bottom` es el punto inferior calibrado.
- `x_top` es el punto superior calibrado.

Esta es la idea central del sistema: convertir desplazamiento crudo en un porcentaje relativo al usuario y a la maquina.

## Por Que La Calibracion Es Por Usuario

Los usuarios no siempre usan los mismos extremos mecanicos:

- diferente longitud corporal
- diferente setup
- posicion de asiento o agarre distinta
- preferencia de no bloquear completamente la articulacion

Sin calibracion, un buen movimiento puede verse como ROM insuficiente o una repeticion mala puede parecer valida.

## Calculo De Velocidad

La velocidad sale del cambio entre muestras:

```text
velocity = (x[k] - x[k - 1]) / dt
```

Si se usa ROM normalizado:

```text
velocity_rom = (rom[k] - rom[k - 1]) / dt
```

Con `dt` cercano a `0.005 s`. La velocidad ayuda a detectar fases y calidad de movimiento.

## Deteccion De Repeticiones

El firmware usa una maquina de estados basada en ROM:

- `Bottom`
- `Ascending`
- `Top`
- `Descending`

Logica simplificada:

1. En bottom espera movimiento real hacia arriba.
2. Si ROM sube consistentemente, entra a ascending.
3. Si alcanza region superior, entra a top.
4. Si ROM baja, entra a descending.
5. Si vuelve abajo y pasa validaciones, cuenta la repeticion.

Una repeticion valida requiere:

- ROM suficiente.
- Llegar cerca del top calibrado.
- Duracion razonable.
- Orden de fases coherente.
- Senal no excesivamente ruidosa.

## Por Que Se Rechazan Reps

Una repeticion puede rechazarse si:

- no alcanza suficiente ROM
- no llega arriba
- se revierte demasiado temprano
- hay ruido fuerte
- dura demasiado poco

Por eso mover la maquina no siempre significa contar una repeticion.

## Pin Load Vs Recomendacion

Pin load es la posicion fisica del selector de peso. Pertenece a la maquina.

Recomendacion es consejo especifico por usuario, calculado desde calibracion o historial.

Ejemplo:

```text
pin load = 20 kg
recomendacion = 25 kg
```

La sesion inicia con 20 kg si el usuario no mueve el pin. El software no puede asumir que el hardware cambio.

## Recomendacion De Carga

El modelo conceptual es:

```text
v = a + bL
```

Donde:

- `v` es velocidad representativa.
- `L` es carga.
- `a` y `b` son constantes ajustadas.

Con datos de velocidad a cargas conocidas, el sistema puede sugerir una siguiente carga.

## Resultado De Calibracion

Una calibracion debe guardar:

- bottom calibrado
- top calibrado
- confianza/calidad
- carga probada
- recomendacion siguiente
- machine type
- user id

Ruta Firebase:

```text
calibrations/{uid}/{machineTypeId}
```

## Flujo Firebase

Al terminar una sesion:

1. El firmware crea el resultado local.
2. Lo guarda en una cola NVS.
3. Un servicio de sync sube por fases.

Fases tipicas:

- session root
- metadata diaria
- timeline
- day summary
- week summary
- set details
- rep sets

Esto evita perder datos y reduce riesgo de bloqueos por payloads grandes.

## Restricciones De Memoria

El ESP32-S3 debe balancear:

- UI LVGL rica
- escrituras Firebase/TLS

Por eso:

- se liberan pantallas opcionales antes de subidas pesadas
- se fragmentan payloads cuando hay poco heap
- se usa cola NVS para reintento
- repSets se dividen en escrituras mas pequenas

## Fuentes De Error

### Error De Alineacion Mecanica

Un sensor o soporte mal alineado causa:

- rango comprimido
- top/bottom inconsistentes
- lecturas ToF malas

### Ruido ADC

Puede causar:

- grafica inestable
- transiciones falsas
- velocidad inconsistente

### Mala Calibracion

Si bottom/top se guardan mal:

- ROM se vuelve enganoso
- reps buenas pueden rechazarse
- top o bottom nunca se alcanzan en software

### Tecnica Del Usuario

Parciales, rebotes, tempo irregular o setup distinto cambian la senal.

### Falla De Red

La sesion puede terminar bien aunque la subida se retrase. Para eso existe la cola local.

### Presion De Memoria

El dispositivo puede tener CPU disponible pero no heap seguro para Firebase. Aparecen delays, chunking o backoff.

## Validar Una Instalacion Nueva

### Hardware

1. Confirma que el sensor de movimiento esta firme.
2. Confirma pantalla y touch.
3. Confirma RFID.
4. Confirma montaje ToF si se usa.

### Senal

1. Mira la grafica al mover la maquina lentamente.
2. Confirma direccion correcta.
3. Confirma que no satura antes de tiempo.
4. Confirma que llega a zonas baja y alta.

### Calibracion

1. Guarda bottom.
2. Guarda top.
3. Mueve la maquina otra vez.
4. Confirma ROM cerca de 0% a 100%.
5. Haz reps suaves y confirma que cuentan.

### Sesion

1. Escanea RFID.
2. Espera user sync.
3. Inicia sesion.
4. Haz reps.
5. Termina sesion.
6. Confirma resumen.
7. Confirma subida Firebase.

## Depurar ROM Incorrecto

1. Verifica si bottom/top se guardaron al reves.
2. Revisa que la maquina llegue a extremos esperados.
3. Revisa si el sensor esta flojo.
4. Observa ruido en grafica.
5. Recalibra con movimiento lento y completo.

## Depurar Pin Load Incorrecto

1. Verifica si el firmware principal esta en modo manual.
2. Confirma que el usuario actualizo botones en pantalla.
3. Si usas ToF, recalibra rangos de distancia.
4. Revisa alineacion del target y holder.

## Explicacion Corta Para Un Nuevo Integrante

```text
SmartGym muestrea movimiento cada 5 ms, suaviza la senal, la convierte a ROM
normalizado, detecta fases de repeticion, registra reps y sets con el pin load
actual, y sube la sesion terminada a Firebase mediante una cola segura.
```

Si alguien entiende esa frase, ya tiene el modelo mental para navegar el sistema.

## Documentos Relacionados

- [README del proyecto](../README.es.md)
- [Arquitectura del sistema](SYSTEM_ARCHITECTURE.es.md)
- [Guia de desarrollador](DEVELOPER_GUIDE.es.md)
- [Guia de Firebase](FIREBASE_GUIDE.es.md)
- [Troubleshooting](TROUBLESHOOTING.es.md)
- [Prototipo de deteccion de peso](../weight_detection/README.es.md)

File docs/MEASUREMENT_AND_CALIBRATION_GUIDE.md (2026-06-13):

# SmartGym Measurement and Calibration Guide

Language: English | [Espanol](MEASUREMENT_AND_CALIBRATION_GUIDE.es.md)

This guide explains how SmartGym measures motion, converts raw sensor readings
into usable biomechanical values, calibrates user ROM, handles pin load, and
detects common error cases. It is written for someone who did not build the
project and needs to understand how the system works end to end.

## Purpose

The firmware must answer these questions during a workout:

- Where is the machine in its stroke right now
- Is the user moving up or down
- Did a valid repetition just happen
- What physical load was on the machine
- What recommendation should be shown next

To answer those questions, SmartGym combines:

- An analog motion sensor on the machine stroke
- User-specific ROM calibration
- A ROM-based repetition state machine
- A machine pin-load model
- Local session recording
- Firebase synchronization

## Big Picture

The measurement pipeline is:

1. Sample the analog motion sensor every 5 ms.
2. Smooth the raw sensor reading with an EMA filter.
3. Convert the filtered reading into a machine position.
4. Normalize that position into percent ROM using the calibrated bottom and top
   points for the active user and machine.
5. Compute velocity from the change in normalized position over time.
6. Run a repetition state machine on the ROM signal.
7. Record accepted reps, sets, timing, pin load, and session metrics.
8. Save the finished session locally and upload it to Firebase in phases.

## Sensor Inputs

### Motion Sensor

The main firmware uses an analog motion sensor connected to GPIO 17 on the
ESP32-S3 display board. The current firmware assumes one primary stroke signal
for the active machine.

The sensor is sampled every 5 ms, which corresponds to about 200 Hz:

```text
sample_interval = 0.005 s
sample_rate = 1 / 0.005 = 200 Hz
```

This rate is fast enough to resolve normal gym-machine motion while still being
practical on an ESP32-S3 that is also running LVGL and Firebase networking.

### RFID

RFID is used to identify the active user. The firmware must know the user
before it can load the correct ROM calibration and recommendation.

### Pin Load

The firmware currently treats machine pin load as machine state, not user
state. In the main firmware, the user updates the current pin load with the
screen buttons. The separate `weight_detection/` folder contains a VL53L0X
prototype for automatic weight-stack detection, but that prototype is not the
main firmware path yet.

## Raw Signal to Position

The analog signal is read by the ESP32-S3 ADC. For a 12-bit ADC, the raw range
is:

```text
0 to 4095 counts
```

If the full machine stroke is treated as 2000 mm, a simple theoretical
resolution estimate is:

```text
resolution_mm = 2000 / 4096 = 0.488 mm per count
```

That is a useful engineering estimate for documentation, although the real
effective resolution depends on sensor noise, mounting, ADC behavior, and the
mechanical linkage.

If the analog voltage is modeled as proportional to stroke position:

```text
position_mm = (adc_or_voltage / full_scale) * stroke_length_mm
```

Where:

- `position_mm` is the estimated position along the stroke
- `adc_or_voltage` is the measured signal
- `full_scale` is the sensor full-scale reference
- `stroke_length_mm` is the machine stroke assumed for conversion

The exact conversion may differ slightly by machine or sensor implementation,
but this is the conceptual model used by the project.

## Filtering

The signal is smoothed with an exponential moving average, or EMA. The project
documentation and firmware behavior use a smoothing factor around:

```text
alpha = 0.50
```

The filter form is:

```text
filtered[k] = alpha * raw[k] + (1 - alpha) * filtered[k - 1]
```

Why this is needed:

- The raw sensor can jitter due to ADC noise
- Mechanical vibration creates false slope changes
- Velocity is a derivative, so it amplifies noise

Too little filtering causes false rep edges and unstable velocity. Too much
filtering causes lag and can flatten short pauses or fast transitions.

## ROM Calibration

ROM calibration is user-specific and machine-type-specific.

The system stores a bottom point and a top point for the active user and the
active machine type. These points define the useful motion span for that user.

### Calibration Inputs

The calibration flow asks the user to:

1. Move to the bottom position and confirm it.
2. Move to the top position and confirm it.
3. Confirm the current pin load.
4. Perform controlled reps.
5. Save the result and recommendation.

### ROM Normalization

Once bottom and top are known, the firmware converts the current stroke
position into percent ROM:

```text
rom_percent = ((x - x_bottom) / (x_top - x_bottom)) * 100
```

Where:

- `x` is the current filtered position
- `x_bottom` is the calibrated bottom point
- `x_top` is the calibrated top point

This normalization is the heart of the system. It lets the firmware compare
reps in a user-relative way instead of relying only on absolute sensor values.

### Why User-Specific Calibration Matters

Different users do not always use identical mechanical endpoints:

- limb length differs
- preferred setup differs
- seat or attachment position may differ
- some users avoid fully locking out

Without user calibration, the same raw stroke can produce misleading ROM
percentages and false judgments about rep quality.

## Velocity Calculation

Velocity is computed from the change in position over time:

```text
velocity = (x[k] - x[k - 1]) / dt
```

If the project is using normalized ROM directly:

```text
velocity_rom = (rom[k] - rom[k - 1]) / dt
```

Where:

- `x[k]` or `rom[k]` is the current sample
- `x[k - 1]` or `rom[k - 1]` is the previous sample
- `dt` is the sample interval, about 0.005 s

The important point is that SmartGym uses motion trend and timing, not only a
single position threshold. That is what enables rep-phase detection and timing
feedback.

## Repetition Detection

The firmware uses a ROM-based state machine. The documented states are:

- `Bottom`
- `Ascending`
- `Top`
- `Descending`

### Simplified Logic

1. At the bottom, the system waits for a meaningful upward movement.
2. If ROM is rising consistently, the rep enters `Ascending`.
3. If the user reaches the upper target region, the rep enters `Top`.
4. When ROM falls again, the rep enters `Descending`.
5. When the user returns to the lower region, the rep can be counted as
   complete if all other validity checks pass.

### What Makes a Rep Valid

A rep is not accepted just because the signal moved. Typical validity checks
include:

- sufficient ROM range
- arrival near the calibrated top point
- reasonable duration
- coherent phase order
- no severe noise or aborted motion

### Why Reps Can Be Rejected

A rep may be rejected for reasons such as:

- the user never reached enough ROM
- the top was not reached
- the motion reversed too early
- the signal was noisy
- the movement duration was too short to be trustworthy

This is why a user can move the machine and still not get a counted rep.

## Set Completion and Session Recording

When valid reps accumulate, the session recorder stores:

- rep number
- set number
- timestamps
- ROM metrics
- timing metrics
- pin load used for that rep
- rep validity and quality information

This design matters because the machine pin load may change during a workout.
The firmware therefore records the load associated with the rep, not just a
single load for the entire session.

## Current Pin Load vs Recommendation

This distinction is essential for understanding SmartGym.

### Pin Load

Pin load is the physical selector position on the machine. It belongs to the
machine state and represents what is actually set at that moment.

### Recommendation

Recommendation is user-specific advice derived from calibration or prior
session data. It does not automatically move the machine pin.

### Practical Example

If the machine is physically set to 20 kg and the active user recommendation is
25 kg:

- pin load remains 20 kg
- recommendation is shown as 25 kg
- the session starts at 20 kg unless the user changes the pin

This separation prevents the software from pretending that physical hardware
changed when it did not.

## Recommendation Generation

The project uses a load-velocity concept for recommendations. The simplified
model is:

```text
v = a + bL
```

Where:

- `v` is a representative movement velocity
- `L` is load
- `a` and `b` are fitted constants

With multiple loads and measured velocities, the firmware can estimate how the
user performs across effort levels and derive a next recommended load. The
exact heuristic may vary by goal, but the core idea is that performance at
known loads informs the next load suggestion.

## Calibration Outcome

A calibration result usually needs to save:

- calibrated bottom position
- calibrated top position
- quality/confidence
- current or tested load
- recommended next load
- machine type identifier
- user identifier

These values are stored under:

```text
calibrations/{uid}/{machineTypeId}
```

## Firebase Data Flow

The upload path is intentionally phased because the ESP32-S3 is memory
constrained during TLS traffic.

When a session finishes:

1. The firmware creates a local session result.
2. The result is stored in an NVS-backed queue.
3. A sync service uploads the session in phases.

Typical phases include:

- session root
- daily metadata
- daily timeline
- daily summary
- weekly summary
- set details
- rep sets

This design prevents a large single upload from blocking the device or losing
data when Wi-Fi is unstable.

## Memory Constraints

The firmware must manage two conflicting needs:

- rich UI behavior with LVGL
- TLS-backed Firebase uploads

To reduce risk:

- optional UI trees are freed before heavy uploads
- uploads are chunked when heap is low
- an NVS queue stores sessions for retry
- large rep-set payloads are split into smaller writes

### Why This Matters

If memory is low and a large payload is sent anyway, the device can freeze,
stall, or fail the upload. This is one of the most important implementation
realities for anyone reproducing the project.

## Error Sources and Failure Modes

### 1. Mechanical Alignment Error

The motion sensor or ToF holder may be mounted at a slightly wrong angle or
position. This causes:

- compressed stroke range
- inconsistent top or bottom detection
- bad ToF target readings

### 2. ADC Noise

Electrical noise can produce jitter in the analog signal. Symptoms include:

- unstable graph lines
- false phase transitions
- inconsistent velocity

### 3. Bad Calibration

If bottom or top are saved incorrectly:

- ROM percentages become misleading
- good reps may be rejected
- top or bottom may never be reached in software

### 4. User Technique Variability

Different body positioning, tempo, partial reps, or bouncing can create signal
patterns that differ from the ideal expected motion.

### 5. Network or Cloud Failure

The workout may finish correctly while the upload is delayed. This is why local
queueing is required.

### 6. Memory Pressure

The ESP32-S3 may have enough CPU to continue running, but not enough safe heap
to perform large Firebase writes. This shows up as delayed uploads, chunking, or
backoff behavior.

## How to Validate a New Installation

If someone new is reproducing the project, this is the recommended validation
sequence.

### Hardware Validation

1. Confirm the motion sensor is physically secure and moves through the full
   machine stroke.
2. Confirm the display boots and touch input works.
3. Confirm RFID reads a test card.
4. Confirm the ToF holder is mounted consistently if the prototype is used.

### Signal Validation

1. Watch the live graph while manually moving the machine slowly.
2. Confirm the raw stroke direction matches the actual machine direction.
3. Confirm the graph is not saturating too early.
4. Confirm the signal reaches both low and high regions cleanly.

### Calibration Validation

1. Save bottom.
2. Save top.
3. Move the machine again.
4. Confirm ROM rises from near 0\% to near 100\%.
5. Perform a few smooth reps and confirm they are accepted.

### Session Validation

1. Scan RFID.
2. Wait for user sync to complete.
3. Start a session.
4. Perform reps.
5. Finish the session.
6. Confirm the summary appears.
7. Confirm the session enters the Firebase queue and eventually uploads.

## How to Debug Wrong ROM

If ROM behaves incorrectly:

1. Check whether bottom and top were saved in the correct order.
2. Check whether the machine stroke actually reaches the expected endpoints.
3. Check whether the sensor is mounted too loosely.
4. Check for severe noise in the graph.
5. Re-run calibration with slow, full-range motion.

## How to Debug Wrong Pin Load

If pin load is wrong:

1. Verify whether the main firmware is in manual pin-load mode.
2. Confirm the user updated the on-screen pin load buttons correctly.
3. If using the prototype ToF module, recalibrate its machine-specific
   distance ranges.
4. Check alignment of the ToF target and holder.

## How to Explain the Project to a New Teammate

A good short explanation is:

```text
SmartGym samples machine motion every 5 ms, smooths the signal, converts it
into normalized ROM, detects rep phases from that ROM, records reps and sets
with the current machine pin load, and then uploads the finished session to
Firebase using a memory-safe queued pipeline.
```

If the new teammate understands that sentence, they have the mental model
needed to navigate the rest of the system.

## Recommended Companion Documents

- [Project README](../README.md)
- [System Architecture](SYSTEM_ARCHITECTURE.md)
- [Developer Guide](DEVELOPER_GUIDE.md)
- [Firebase Guide](FIREBASE_GUIDE.md)
- [Troubleshooting Guide](TROUBLESHOOTING.md)
- [Weight Detection Prototype](../weight_detection/README.md)

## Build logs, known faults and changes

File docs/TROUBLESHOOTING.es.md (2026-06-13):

# Guia De Troubleshooting SmartGym

Idioma: [English](TROUBLESHOOTING.md) | Espanol

## Build Falla

Ejecuta:

```powershell
python -m platformio run --environment BOARD_VIEWE_UEDX80480070E_WB_A
```

Revisa:

- PlatformIO instalado.
- Nombre de environment correcto.
- Dependencias descargadas.
- Cambios locales completos.

## Puerto COM Ocupado

Sintomas:

- Upload falla con access denied.
- Monitor serial no abre.

Solucion:

- Cierra monitores seriales.
- Cierra Arduino IDE u otra terminal.
- Desconecta/reconecta ESP32.
- Reintenta upload.

## Upload Falla

- Confirma que el cable USB soporta datos.
- Confirma board/puerto correcto.
- Mantén BOOT si tu board lo requiere.
- Baja velocidad de upload si hace falta.

## Touch No Responde

- Confirma inicializacion LVGL/display.
- Revisa logs de boot.
- Reinicia el dispositivo.

## RFID No Detectado

- Confirma cableado MFRC522.
- Revisa pines SPI RFID.
- Acerca la tarjeta.
- Evita escanear durante upload activo.

## Wi-Fi No Conecta

- Revisa SSID/password configurados localmente.
- Confirma red 2.4 GHz.
- Revisa logs Wi-Fi.

## Firebase Falla

- Confirma URL/token/config.
- Confirma Wi-Fi.
- Revisa reglas RTDB.
- Revisa logs `[CloudWrite]`, `[SYNC]`, `[USER_SYNC]`.

## Cola Sync Atorada

Busca:

- `[SYNC] queue upload delayed`
- `[SYNC] upload memory mode=critical`
- logs de queue count

Mantén el dispositivo encendido hasta que drene la cola.

## NVS NOT_ENOUGH_SPACE

Causa:

- demasiadas escrituras en cola o payloads

Mitigacion:

- firmware usa checks de capacidad y chunking
- deja drenar la cola
- evita saltar summary repetidamente en builds viejos

## repSets Retrasados Por Heap

Causa:

- presion de memoria Firebase/TLS
- PATCH grande de repSet

Comportamiento esperado:

- firmware divide repSets bajo memoria restringida
- upload debe llegar a `webapp upload phase=complete`

## Grafica O ROM Incorrecto

- Recalibra ROM.
- Revisa cableado del sensor.
- Confirma direccion/inversion.
- Revisa si se cargo calibracion de usuario.

## Rep No Contada

Causas posibles:

- ROM corto.
- Top/bottom no alcanzado.
- Movimiento rapido o ruidoso.
- Calibracion incorrecta.

Haz reps suaves con rango completo.

## Freeze Al Cancelar Calibracion

- Revisa logs `[CAL]`, `[CAL_UI]` y destruccion de UI.
- Reinicia si hace falta.
- Verifica que no se hayan introducido punteros LVGL obsoletos.

## Dashboard Sin Datos

Revisa:

- UID RFID correcto.
- Ruta bajo `athleteWeeklySessions/{uid}`.
- Upload llego a `phase=complete`.
- Consola del navegador por permisos Firebase.
- Config Firebase dashboard coincide con la base del firmware.

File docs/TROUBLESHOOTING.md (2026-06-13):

# SmartGym Troubleshooting Guide

Language: English | [Espanol](TROUBLESHOOTING.es.md)

## Build Fails

Run:

```powershell
python -m platformio run --environment BOARD_VIEWE_UEDX80480070E_WB_A
```

Check:

- PlatformIO is installed.
- Board environment name is correct.
- Dependencies downloaded correctly.
- No local syntax changes are incomplete.

## COM Port Busy

Symptoms:

- Upload fails with access denied.
- Monitor cannot open serial port.

Fix:

- Close any open serial monitor.
- Close Arduino IDE or other terminal using the port.
- Unplug/replug the ESP32.
- Retry upload.

## Upload Fails

- Confirm USB cable supports data.
- Confirm correct board/port.
- Try holding BOOT if required by the board.
- Lower upload speed if needed.

## Touch Not Responding

- Confirm LVGL/display initialization succeeded.
- Check serial boot logs.
- Reboot the device.

## RFID Not Detected

- Confirm MFRC522 wiring.
- Check RFID SPI pins.
- Hold card close to the reader.
- Avoid scanning during active upload if firmware is blocking RFID for safety.

## Wi-Fi Not Connected

- Check configured SSID/password build flags.
- Confirm network is 2.4 GHz.
- Check serial Wi-Fi logs.

## Firebase Read/Write Fails

- Confirm database URL and token/config.
- Confirm Wi-Fi is connected.
- Check Firebase RTDB rules.
- Check serial tags `[CloudWrite]`, `[SYNC]`, and `[USER_SYNC]`.

## Sync Queue Stuck

Look for:

- `[SYNC] queue upload delayed`
- `[SYNC] upload memory mode=critical`
- NVS queue count logs.

Keep the device powered until it drains the queue.

## NVS NOT_ENOUGH_SPACE

Cause:

- Too many queued writes or payloads.

Mitigation:

- Firmware uses queue capacity checks and chunking.
- Avoid repeatedly skipping summary during active upload if testing older builds.
- Let the queue drain.

## repSets Upload Delayed by Heap Guard

Cause:

- Firebase/TLS memory pressure.
- Large repSet PATCH payload.

Expected behavior:

- Firmware should split repSets into smaller chunks under constrained memory.
- Upload should eventually reach `webapp upload phase=complete`.

## Graph Clipping or Wrong ROM

- Recalibrate ROM.
- Check sensor wiring.
- Confirm sensor direction/inversion.
- Check whether user calibration was loaded.

## Rep Not Counted

Possible causes:

- ROM too short.
- Top/bottom not reached.
- Motion too fast/noisy.
- Calibration mismatch.

Try smooth reps through full range.

## Calibration Cancel Freeze

If calibration does not return safely:

- Check serial logs around `[CAL]`, `[CAL_UI]`, and UI destroy paths.
- Reboot device if needed.
- Verify no stale LVGL pointer accesses were introduced.

## Dashboard Missing Data

Check:

- Correct RFID UID selected.
- Firebase path exists under `athleteWeeklySessions/{uid}`.
- Session upload reached `phase=complete`.
- Browser console for Firebase permission errors.
- Dashboard Firebase config matches firmware database.

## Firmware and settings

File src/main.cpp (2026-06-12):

#include <Arduino.h>
#include <esp_display_panel.hpp>
#include <lvgl.h>
#include "SmartGymTouchApp.h"
#include "lvgl_v8_port.h"

using namespace esp_panel::drivers;
using namespace esp_panel::board;

namespace {
SmartGymTouchApp app;
constexpr uint16_t kRgbBounceBufferLines = 20;
constexpr int kBacklightBrightnessPercent = 100;
}

void setup() {
  Serial.begin(115200);
  delay(200);

  Board* board = new Board();
  board->init();
#if LVGL_PORT_AVOID_TEARING_MODE
  auto lcd = board->getLCD();
  lcd->configFrameBufferNumber(LVGL_PORT_DISP_BUFFER_NUM);
#if ESP_PANEL_DRIVERS_BUS_ENABLE_RGB && CONFIG_IDF_TARGET_ESP32S3
  auto lcd_bus = lcd->getBus();
  if (lcd_bus->getBasicAttributes().type == ESP_PANEL_BUS_TYPE_RGB) {
    // ESP32-S3 RGB panels can visibly drift/tear when PSRAM is busy with
    // WiFi/TLS. Viewe/Espressif recommend width*10 by default and width*20
    // when drift persists.
    static_cast<BusRGB*>(lcd_bus)->configRGB_BounceBufferSize(
        lcd->getFrameWidth() * kRgbBounceBufferLines);
  }
#endif
#endif
  const bool boardReady = board->begin();
  assert(boardReady);

  if (auto* backlight = board->getBacklight(); backlight != nullptr) {
    backlight->setBrightness(kBacklightBrightnessPercent);
  }

  lvgl_port_init(board->getLCD(), board->getTouch());

  lvgl_port_lock(-1);
  app.begin();
  lvgl_port_unlock();
}

void loop() {
  delay(1);
}

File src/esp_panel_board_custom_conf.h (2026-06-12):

/*
 * SPDX-FileCopyrightText: 2023-2025 Espressif Systems (Shanghai) CO LTD
 *
 * SPDX-License-Identifier: Apache-2.0
 */
/**
 * @file   esp_panel_board_custom_conf.h
 * @brief  Custom board configuration for Viewe UEDX80480070E-WB-A
 */

#pragma once

// *INDENT-OFF*

#ifndef ESP_PANEL_BOARD_DEFAULT_USE_CUSTOM
#define ESP_PANEL_BOARD_DEFAULT_USE_CUSTOM  (1)
#endif

#if ESP_PANEL_BOARD_DEFAULT_USE_CUSTOM

#define ESP_PANEL_BOARD_NAME                "Viewe:UEDX80480070E-WB-A"
#define ESP_PANEL_BOARD_WIDTH               (800)
#define ESP_PANEL_BOARD_HEIGHT              (480)

#define ESP_PANEL_BOARD_USE_LCD             (1)

#if ESP_PANEL_BOARD_USE_LCD
#define ESP_PANEL_BOARD_LCD_CONTROLLER      ST7262
#define ESP_PANEL_BOARD_LCD_BUS_TYPE        (ESP_PANEL_BUS_TYPE_RGB)

#if ESP_PANEL_BOARD_LCD_BUS_TYPE == ESP_PANEL_BUS_TYPE_RGB
#define ESP_PANEL_BOARD_LCD_RGB_USE_CONTROL_PANEL       (0)
#define ESP_PANEL_BOARD_LCD_RGB_CLK_HZ                  (16 * 1000 * 1000)
#define ESP_PANEL_BOARD_LCD_RGB_HPW                     (48)
#define ESP_PANEL_BOARD_LCD_RGB_HBP                     (40)
#define ESP_PANEL_BOARD_LCD_RGB_HFP                     (88)
#define ESP_PANEL_BOARD_LCD_RGB_VPW                     (6)
#define ESP_PANEL_BOARD_LCD_RGB_VBP                     (26)
#define ESP_PANEL_BOARD_LCD_RGB_VFP                     (10)
#define ESP_PANEL_BOARD_LCD_RGB_PCLK_ACTIVE_NEG         (1)
#define ESP_PANEL_BOARD_LCD_RGB_DATA_WIDTH              (16)
#define ESP_PANEL_BOARD_LCD_RGB_PIXEL_BITS              (ESP_PANEL_LCD_COLOR_BITS_RGB565)
#define ESP_PANEL_BOARD_LCD_RGB_BOUNCE_BUF_SIZE         (ESP_PANEL_BOARD_WIDTH * 20)
#define ESP_PANEL_BOARD_LCD_RGB_IO_HSYNC                (39)
#define ESP_PANEL_BOARD_LCD_RGB_IO_VSYNC                (41)
#define ESP_PANEL_BOARD_LCD_RGB_IO_DE                   (40)
#define ESP_PANEL_BOARD_LCD_RGB_IO_PCLK                 (42)
#define ESP_PANEL_BOARD_LCD_RGB_IO_DISP                 (-1)
#define ESP_PANEL_BOARD_LCD_RGB_IO_DATA0                (8)
#define ESP_PANEL_BOARD_LCD_RGB_IO_DATA1                (3)
#define ESP_PANEL_BOARD_LCD_RGB_IO_DATA2                (46)
#define ESP_PANEL_BOARD_LCD_RGB_IO_DATA3                (9)
#define ESP_PANEL_BOARD_LCD_RGB_IO_DATA4                (1)
#define ESP_PANEL_BOARD_LCD_RGB_IO_DATA5                (5)
#define ESP_PANEL_BOARD_LCD_RGB_IO_DATA6                (6)
#define ESP_PANEL_BOARD_LCD_RGB_IO_DATA7                (7)
#if ESP_PANEL_BOARD_LCD_RGB_DATA_WIDTH > 8
#define ESP_PANEL_BOARD_LCD_RGB_IO_DATA8                (15)
#define ESP_PANEL_BOARD_LCD_RGB_IO_DATA9                (16)
#define ESP_PANEL_BOARD_LCD_RGB_IO_DATA10               (4)
#define ESP_PANEL_BOARD_LCD_RGB_IO_DATA11               (45)
#define ESP_PANEL_BOARD_LCD_RGB_IO_DATA12               (48)
#define ESP_PANEL_BOARD_LCD_RGB_IO_DATA13               (47)
#define ESP_PANEL_BOARD_LCD_RGB_IO_DATA14               (21)
#define ESP_PANEL_BOARD_LCD_RGB_IO_DATA15               (14)
#endif
#endif

#define ESP_PANEL_BOARD_LCD_COLOR_BITS          (ESP_PANEL_LCD_COLOR_BITS_RGB565)
#define ESP_PANEL_BOARD_LCD_COLOR_BGR_ORDER     (0)
#define ESP_PANEL_BOARD_LCD_COLOR_INEVRT_BIT    (0)
#define ESP_PANEL_BOARD_LCD_SWAP_XY             (0)
#define ESP_PANEL_BOARD_LCD_MIRROR_X            (0)
#define ESP_PANEL_BOARD_LCD_MIRROR_Y            (0)
#define ESP_PANEL_BOARD_LCD_GAP_X               (0)
#define ESP_PANEL_BOARD_LCD_GAP_Y               (0)
#define ESP_PANEL_BOARD_LCD_RST_IO              (-1)
#define ESP_PANEL_BOARD_LCD_RST_LEVEL           (0)
#endif

#define ESP_PANEL_BOARD_USE_TOUCH               (1)

#if ESP_PANEL_BOARD_USE_TOUCH
#define ESP_PANEL_BOARD_TOUCH_CONTROLLER        GT911
#define ESP_PANEL_BOARD_TOUCH_BUS_TYPE          (ESP_PANEL_BUS_TYPE_I2C)
#define ESP_PANEL_BOARD_TOUCH_BUS_SKIP_INIT_HOST        (0)

#if ESP_PANEL_BOARD_TOUCH_BUS_TYPE == ESP_PANEL_BUS_TYPE_I2C
#define ESP_PANEL_BOARD_TOUCH_I2C_HOST_ID               (0)
#if !ESP_PANEL_BOARD_TOUCH_BUS_SKIP_INIT_HOST
#define ESP_PANEL_BOARD_TOUCH_I2C_CLK_HZ                (400 * 1000)
#define ESP_PANEL_BOARD_TOUCH_I2C_SCL_PULLUP            (1)
#define ESP_PANEL_BOARD_TOUCH_I2C_SDA_PULLUP            (1)
#define ESP_PANEL_BOARD_TOUCH_I2C_IO_SCL                (20)
#define ESP_PANEL_BOARD_TOUCH_I2C_IO_SDA                (19)
#endif
#define ESP_PANEL_BOARD_TOUCH_I2C_ADDRESS               (0)
#endif

#define ESP_PANEL_BOARD_TOUCH_SWAP_XY           (0)
#define ESP_PANEL_BOARD_TOUCH_MIRROR_X          (0)
#define ESP_PANEL_BOARD_TOUCH_MIRROR_Y          (0)
#define ESP_PANEL_BOARD_TOUCH_RST_IO            (-1)
#define ESP_PANEL_BOARD_TOUCH_RST_LEVEL         (0)
#define ESP_PANEL_BOARD_TOUCH_INT_IO            (-1)
#define ESP_PANEL_BOARD_TOUCH_INT_LEVEL         (0)
#endif

#define ESP_PANEL_BOARD_USE_BACKLIGHT           (1)
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

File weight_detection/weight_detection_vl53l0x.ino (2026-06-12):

#include <Wire.h>
#include "Adafruit_VL53L0X.h"

// Standalone prototype for detecting a selectorized weight-stack position
// with a VL53L0X time-of-flight distance sensor.

Adafruit_VL53L0X lox = Adafruit_VL53L0X();

const int NUM_MUESTRAS = 30;
const int SDA_PIN = 21;
const int SCL_PIN = 22;

float distanciaPromedioCm = 0.0f;

int pesoDetectado = 0;
int stackDetectado = 0;
int pesoFinal = 0;

const int NUM_CONFIRMACIONES = 5;
int ultimoPesoTemporal = 0;
int contadorConfirmacion = 0;
long sumaPesoFinal = 0;

String estado = "Inicializando...";
String estadoPesoFinal = "Esperando confirmacion...";

void iniciarVL53L0X() {
  Wire.begin(SDA_PIN, SCL_PIN);

  if (!lox.begin()) {
    Serial.println("Error: No se detecto el VL53L0X.");
    Serial.println("Revisa conexiones:");
    Serial.println("VCC -> 3.3V");
    Serial.println("GND -> GND");
    Serial.println("SDA -> GPIO 21");
    Serial.println("SCL -> GPIO 22");

    while (1) {
      delay(100);
    }
  }

  Serial.println("VL53L0X detectado correctamente.");
}

float leerDistanciaCm() {
  VL53L0X_RangingMeasurementData_t measure;

  lox.rangingTest(&measure, false);

  if (measure.RangeStatus != 4) {
    return measure.RangeMilliMeter / 10.0f;
  }

  return -1.0f;
}

float leerPromedioDistanciaCm() {
  float suma = 0.0f;
  int lecturasValidas = 0;

  for (int i = 0; i < NUM_MUESTRAS; i++) {
    float d = leerDistanciaCm();

    if (d > 0.0f && d < 200.0f) {
      suma += d;
      lecturasValidas++;
    }

    delay(20);
  }

  if (lecturasValidas == 0) {
    return -1.0f;
  }

  return suma / lecturasValidas;
}

void detectarPesoPorDistancia(float distanciaCm) {
  pesoDetectado = 0;
  stackDetectado = 0;

  if (distanciaCm < 0.0f) {
    estado = "Lectura invalida o fuera de rango";
    return;
  }

  if (distanciaCm >= 0.00f && distanciaCm < 2.00f) {
    pesoDetectado = 220;
    stackDetectado = 1;
  } else if (distanciaCm >= 4.00f && distanciaCm < 6.00f) {
    pesoDetectado = 205;
    stackDetectado = 2;
  } else if (distanciaCm >= 7.00f && distanciaCm < 8.00f) {
    pesoDetectado = 190;
    stackDetectado = 3;
  } else if (distanciaCm >= 8.20f && distanciaCm < 9.00f) {
    pesoDetectado = 175;
    stackDetectado = 4;
  } else if (distanciaCm >= 9.90f && distanciaCm < 11.00f) {
    pesoDetectado = 160;
    stackDetectado = 5;
  } else if (distanciaCm >= 12.00f && distanciaCm < 13.50f) {
    pesoDetectado = 145;
    stackDetectado = 6;
  } else if (distanciaCm >= 14.50f && distanciaCm < 15.50f) {
    pesoDetectado = 130;
    stackDetectado = 7;
  } else if (distanciaCm >= 16.80f && distanciaCm < 17.50f) {
    pesoDetectado = 115;
    stackDetectado = 8;
  } else if (distanciaCm >= 18.60f && distanciaCm < 19.80f) {
    pesoDetectado = 100;
    stackDetectado = 9;
  } else if (distanciaCm >= 20.60f && distanciaCm < 21.50f) {
    pesoDetectado = 85;
    stackDetectado = 10;
  } else if (distanciaCm >= 21.90f && distanciaCm < 22.90f) {
    pesoDetectado = 70;
    stackDetectado = 11;
  } else if (distanciaCm >= 23.00f && distanciaCm < 24.00f) {
    pesoDetectado = 55;
    stackDetectado = 12;
  } else if (distanciaCm >= 24.20f && distanciaCm < 24.60f) {
    pesoDetectado = 40;
    stackDetectado = 13;
  } else if (distanciaCm >= 24.61f && distanciaCm < 25.25f) {
    pesoDetectado = 25;
    stackDetectado = 14;
  } else if (distanciaCm >= 25.35f && distanciaCm < 41.25f) {
    pesoDetectado = 10;
    stackDetectado = 15;
  } else {
    pesoDetectado = 0;
    stackDetectado = 0;
    estado = "Distancia fuera de los rangos configurados";
    return;
  }

  estado = "Peso detectado correctamente";
}

void actualizarPesoFinal() {
  if (pesoDetectado <= 0) {
    ultimoPesoTemporal = 0;
    contadorConfirmacion = 0;
    sumaPesoFinal = 0;
    estadoPesoFinal = "Esperando peso valido...";
    return;
  }

  if (pesoDetectado != ultimoPesoTemporal) {
    ultimoPesoTemporal = pesoDetectado;
    contadorConfirmacion = 1;
    sumaPesoFinal = pesoDetectado;
    estadoPesoFinal = "Confirmando nuevo peso...";
    return;
  }

  contadorConfirmacion++;
  sumaPesoFinal += pesoDetectado;

  if (contadorConfirmacion >= NUM_CONFIRMACIONES) {
    pesoFinal = sumaPesoFinal / contadorConfirmacion;
    estadoPesoFinal = "Peso final confirmado";

    contadorConfirmacion = NUM_CONFIRMACIONES;
    sumaPesoFinal = static_cast<long>(pesoFinal) * NUM_CONFIRMACIONES;
  }
}

void actualizarMedicionPeso() {
  distanciaPromedioCm = leerPromedioDistanciaCm();
  detectarPesoPorDistancia(distanciaPromedioCm);
  actualizarPesoFinal();
}

void imprimirDatosPeso() {
  Serial.println("==============================");

  Serial.print("Distancia promedio: ");
  if (distanciaPromedioCm > 0.0f) {
    Serial.print(distanciaPromedioCm, 2);
    Serial.println(" cm");
  } else {
    Serial.println("Lectura invalida");
  }

  Serial.print("Peso detectado: ");
  if (pesoDetectado > 0) {
    Serial.print(pesoDetectado);
    Serial.println(" lb");
  } else {
    Serial.println("No detectado");
  }

  Serial.print("Valor final: ");
  if (pesoFinal > 0) {
    Serial.print(pesoFinal);
    Serial.println(" lb");
  } else {
    Serial.println("No confirmado");
  }

  Serial.print("Confirmacion: ");
  Serial.print(contadorConfirmacion);
  Serial.print(" / ");
  Serial.println(NUM_CONFIRMACIONES);

  Serial.print("Stack detectado: ");
  if (stackDetectado > 0) {
    Serial.println(stackDetectado);
  } else {
    Serial.println("Ninguno");
  }

  Serial.print("Estado: ");
  Serial.println(estado);

  Serial.print("Estado valor final: ");
  Serial.println(estadoPesoFinal);
}

void setup() {
  Serial.begin(115200);
  delay(1000);

  Serial.println("Iniciando sistema de deteccion de peso...");
  iniciarVL53L0X();

  estado = "Sistema listo";
}

void loop() {
  actualizarMedicionPeso();
  imprimirDatosPeso();

  delay(100);
}

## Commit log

2026-06-12 Release SmartGym v1.0 prototype
    [partitions_16mb_ffat.csv]
2026-06-12 Add prototype CAD files
    [encodermount.SLDPRT, encodermount.STL, gymmachineclamp.SLDPRT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]
2026-06-13 Add ToF sensor CAD files
    [Fastener.step, Fastener.stl, Target.step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]
2026-06-13 Add bilingual public documentation
    [machineCatalog_value_only.json, machine_catalog_v1.json]
